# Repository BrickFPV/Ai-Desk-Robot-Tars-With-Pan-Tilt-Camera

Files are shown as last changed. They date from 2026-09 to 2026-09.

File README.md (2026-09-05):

# Tars AI Desk Robot
I wanted to create a sarcastic desk robot inspired from interstellar and also inspired from [Gptars on Youtube](https://www.youtube.com/@gptars) that you can ask things, chat with it, ask what is going on with the enviroment via camera that he can look around with 2 servos. And here it is. I didn't made a 3d printed case for it, I used lego technic to make a chasis. Total cost is about 80 dolars Now, here is step by step guide on how to make this robot:

### Please note that I haven't finished this project yet. So there might be some bugs.

## Features

- 🎤**Voice Interaction:** Low-latency STT via Whisper-large-v3-turbo and Orpheus TTS via Groq.
- 📸**Vision Recognition:** Qwen 2.5 72B vision integration to analyze camera input upon voice triggers.
- ⚙️ **Servo Control:** Smooth pan/tilt tracking via PCA9685 PWM driver board.
- 🌐**Web Search Integration:** Real-time information querying via DuckDuckGo Search API.
- 🔊**Pre-recorded Local Acknowledgments:** Pre-generated TTS wake-word acknowledgments to save API quota.

## **🔌 Needed Hardware**

- Raspberry Pi 4 1gb(Any other raspberry pi with atleast 1gb ram should work. I recommend having a heatsink or a cooler fan)
- Web cam(I used Logitech C270 but you can use any webcam that has a mic.)
- 2 Sg90 Servo Motors
- PCA9685 for controlling the servos
- 1s Lipo or 18650 li-on battery or a trustable 5V power source.
- MT3608(set the output to 5/5,1 volts) if you are using a lipo or 18650 because they output 4.2V max.(Look at **How to fix MT3608** part if the potentiometer on the board doesn't change the output voltage)
- MAX98357A amplifier
- Small speaker for the amp
- Breadboard
- 3D printed parts. Download links will be in the **Downloadables** folder.
- Lego techinc to make the chasis. The lego model will be in the **Downloadables** folder. (i would be pleased if someone makes a 3d printed chasis)

## **Setting Up The Chasis**

legorender
legorender_2
legorender_3

### Step 1: 3D printing and making the servo to be able to connect with lego
First, you need to download and 3D print the stl files (print both of them atleast 2 times because you have two servos with PLA [here](downloadables/3dprint).

After that, you have to screw both the servos to the SG90 shell using the small screws you get when buying a sg90 servo motor.(Make sure the output side on the servo is next to the 2 holes)

Then, put some super glue on the SG90 to lego's middle hole on the side where you can put it to sg90's output. after you put some super glue in the hole, put the Sg90-lego adapter(middle hole where you put glue on) to 
servo's output. Make sure to not push too much as if the glue touches the blue servo motor case, it might glue the motor output and the case and make it not moveable.


 
Adsız

### Step 2: Building the chasis

Download the [lego.io](downloadables/lego.io) Also, download Studio 2.0 from bricklink's [official website](https://store.bricklink.com/v2/studio/download.page)
You can look at the model there and improvise. You don't need to make the same thing. After making the chasis, and pan/tilt sections, fix the webcam on top of the pan section with rubber bands like this:




Then, asemble the two pieces(pan/tilt with camera) together like this:





After that, you can assemble the pan/tilt section with the servo motor on the main body. And after you do the wiring that i explain bellow, it should look like this: 







## **⚡ Wiring**

Here is the Raspberry pi 4 pinout to make things easier.
GPIO-Pinout-Diagram-2

First, just like in any other project, wire GND(PIN 6) to a power rail.

### The wiring for MAX98357a will be like this:

Vin ------ PIN 2(5V power)

Gnd ------ GND power rail

SD  ------ Empty

Gain ----- Gnd power rail

DIN ------ GPIO 21(PIN 40)

BCLK ----- GPIO 18(PIN 12)

LRC ------ GPIO 19(PIN 35)

Output + = Speaker +

Output - = Speaker -

### ---------------------The wiring for PCA9685:-------------------------

 Gnd ----- Gnd power rail
 
 Oe ------ Empty
 
 SCL ----- GPIO 3(PIN 5)
 
 SDA ----- GPIO 2(PIN 3)
 
 VCC ----- 3v3 power (PIN 1)
 
 Power terminal V+ = External 5v power source or 1s lipo wired to Mt3608(output voltage must be set to 5/5,1 volts)
 
 Power terminal - = External 5v power source or 1s lipo wired to Mt3608(output voltage must be set to 5/5,1 volts)

 **IMPORTANT: DO NOT WIRE THE POWER TERMINALS DIRECTLY TO 5V POWER ON RASPBERRY PI AS IT WILL DRAW TOO MUCH POWER AND MAY BURN YOUR BOARD**

 Pan Servo motor = The 3 pins on the very left(Match the colors)
 
 Tilt Servo motor = The 3 pins right next to the pan servo motor pins(Match the colors)servo

 ### ----------------------📷 Wiring for the usb webcam---------------

 Just plug the usb to the raspberry pi :)

## **🔧 How to fix MT3608**

If the potentiometer on the MT3608 doesn't change the output voltage, add a solder bridge at the back of the board as shown on the picture.

mt fix

## 🚀Setup

### Notes before we begin
#### *Get a free api key [here](https://groq.com)*
#### *Make sure you have [Raspberry Pi Connect](https://connect.raspberrypi.com) ready to make things easier*

(I will make an installer in the future)

*Assuming that you have raspberry pi os flashed and ready.(With gui you can disable the gui in the future if you want)*

Run the following commands in the Raspberry Pi terminal to enable the I2C interface for servo driving and install system audio/video dependencies:

```
sudo raspi-config nonint do_i2c 0
sudo apt update
sudo apt install -y python3-pip python3-venv python3-dev portaudio19-dev libasound2-dev alsa-utils ffmpeg vlc
```

Then, create the project workspace and install the libraries:

```
mkdir -p ~/tars_robot && cd ~/tars_robot
python3 -m venv venv
source venv/bin/activate
pip install --upgrade pip
pip install groq opencv-python pyaudio numpy adafruit-circuitpython-servokit duckduckgo_search
```

Create the main application file inside ~/tars_robot/tars.py:

```
nano tars.py
```

Copy and paste the tars.py code from [here](tars.py). And replace **PLACE YOUR GROQ API KEY HERE** on **line 82** with your Groq api key and save(Ctrl+O, Enter, Ctrl+X).

### ⚠DON'T RUN THE CODE YET

Create the generate_acks.py to generate "HUH?","YES?","THATS ME" and other bunch of words when you say "Hey Tars" and paste [this code](generate_acks.py)

**Again, replace "PLACE YOUR GROQ API KEY HERE" on line 5 with your Groq api key**

```
nano generate_acks.py
```

Now, make sure you are on (venv):

```
source venv/bin/activate
```

Then, run generate_acks.py **ONE** time:

```
python generate_acks.py
```

Now, you can run tars.py in (venv) whenever you want:

```
python tars.py
```

### Continue this guide if you want a shortcut and not get into (venv) when you want to run the code!

Exit from (venv):

```
deactivate
```

Create a shell script named run_tars.sh inside your project directory:

```
nano ~/run_tars.sh
```

Paste the following contents (update /home/pi/tars to your actual project folder path):

```
#!/bin/bash
cd /home/pi/tars
source venv/bin/activate
python tars.py

# Keeps the terminal window open if the script exits or crashes
echo ""
read -p "Press [Enter] to close..."
```

Make the script executable:

```
chmod +x ~/run_tars.sh
```

Create a file named TARS.desktop in your desktop. Open it with text editor and paste this code:

### **Replace "YOURUSERNAME" with opperating systems username**

```
[Desktop Entry]
Type=Application
Name=TARS Robot
Comment=Start TARS Voice & Vision Assistant
Exec=/home/YOURUSERNAME/run_tars.sh
Icon=utilities-terminal
Terminal=true
Categories=Development;
```

Make the shortcut file executable:

```
chmod +x ~/Desktop/TARS.desktop
```

Now you can double click and launch tars easily.

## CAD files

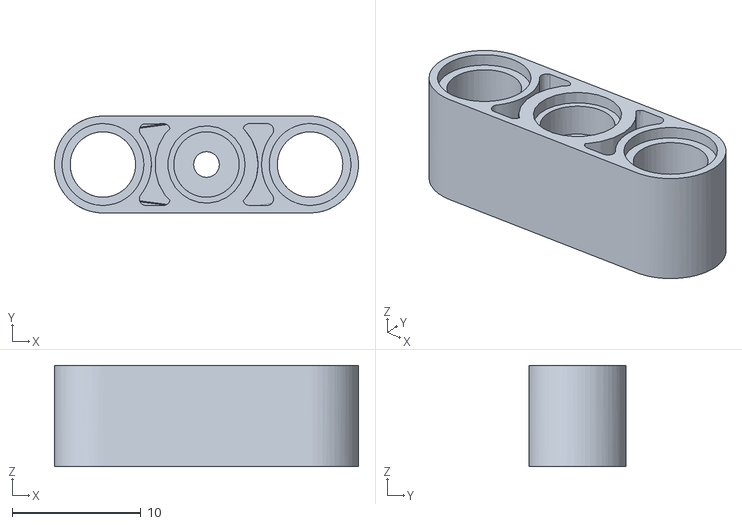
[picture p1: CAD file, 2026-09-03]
downloadables/3dprint/SG90 to lego.stl
23.6 x 7.52 x 7.85

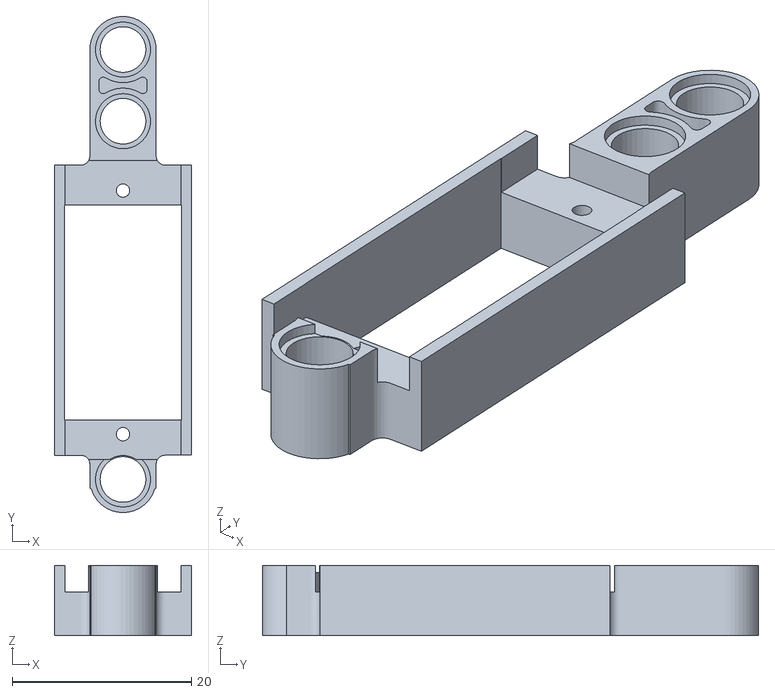
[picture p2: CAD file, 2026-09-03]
downloadables/3dprint/SG90 Shell.stl
15.3 x 55.4 x 7.85

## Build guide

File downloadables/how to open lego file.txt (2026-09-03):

To open the lego chasis file, download Studio 2.0 from bricklink's official site: https://store.bricklink.com/v2/studio/download.page

Then open the lego.io file in the Studio App.

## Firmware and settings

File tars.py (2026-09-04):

import asyncio
import io
import os
import sys
import wave
import subprocess
import ctypes
import random
import time
import json
import base64
import cv2
import numpy as np
import pyaudio
from datetime import datetime, timezone, timedelta

# Improved import order for ddgs library
try:
    from ddgs import DDGS
except ImportError:
    from duckduckgo_search import DDGS

from groq import AsyncGroq
from contextlib import contextmanager

# --- SERVO CONTROLLER (PCA9685 via ServoKit) ---
SERVO_ENABLED = False
try:
    from adafruit_servokit import ServoKit
    kit = ServoKit(channels=16)
    SERVO_ENABLED = True
    print("[PCA9685 Servo Controller Initialized Successfully]")
except Exception as e:
    print(f"[PCA9685 Servo Warning]: Could not initialize ServoKit ({e}). Servos disabled.")

# --- C-LEVEL ALSA ERROR SUPPRESSION ---
ERROR_HANDLER_FUNC = ctypes.CFUNCTYPE(None, ctypes.c_char_p, ctypes.c_int, ctypes.c_char_p, ctypes.c_int, ctypes.c_char_p)
def py_error_handler(filename, line, function, err, fmt):
    pass
c_error_handler = ERROR_HANDLER_FUNC(py_error_handler)

try:
    asound = ctypes.cdll.LoadLibrary('libasound.so.2')
    asound.snd_lib_error_set_handler(c_error_handler)
except Exception:
    pass

os.environ["PA_ALSA_PLUGINS_DISABLE"] = "1"
os.environ["PYTHONUNBUFFERED"] = "1"

# Keywords that trigger playback interruption during TTS speech
INTERRUPT_KEYWORDS = ["hey tars", "tars", "stop", "wait"]

# Keywords that trigger returning to wake-word standby mode
EXIT_KEYWORDS = [
    "stop the conversation", "stop conversation", "stop", 
    "cancel", "never mind", "nevermind", "exit", "bye", "goodbye", "go to standby"
]

def is_exit_command(text: str) -> bool:
    """Checks if user prompt requests ending the conversation session."""
    text_lower = text.lower().strip()
    return any(kw in text_lower for kw in EXIT_KEYWORDS)


@contextmanager
def suppress_stderr():
    """Redirects low-level ALSA/PyAudio stderr warnings to /dev/null."""
    try:
        null_fd = os.open(os.devnull, os.O_WRONLY)
        old_stderr = os.dup(2)
        os.dup2(null_fd, 2)
        os.close(null_fd)
        yield
    finally:
        os.dup2(old_stderr, 2)
        os.close(old_stderr)

# ==========================================
# --- CONFIGURATION & KEYS -----------------
# PLACE YOUR GROQ API KEY
GROQ_API_KEY = "PLACE YOUR GROQ API KEY HERE"

# Groq Orpheus TTS Voice Options: "troy", "daniel", "austin", "hannah", "diana", "autumn"
GROQ_TTS_MODEL = "canopylabs/orpheus-v1-english"
GROQ_TTS_VOICE = "troy"

TURKEY_TZ = timezone(timedelta(hours=3))
ACK_DIR = os.path.join(os.path.dirname(__file__), "acks")
TEMP_WAV_PATH = "/tmp/tars_tts_speech.wav"

# VAD Tuning Parameters
SILENCE_THRESHOLD = 400     # Silence threshold for user speech
INTERRUPT_THRESHOLD = 1200  # Voice threshold to trigger interruption during TTS output
SILENCE_DURATION = 0.6      # Seconds of silence before stopping recording early
MAX_RECORD_TIME = 6.0       # Maximum clip duration hard limit

# Servo Motion Calibration - MAXIMUM RANGE LIMITS
PAN_CHANNEL = 0
TILT_CHANNEL = 1

PAN_CENTER = 90
TILT_CENTER = 90

PAN_RIGHT = 20    # Maximum right limit
PAN_LEFT = 160    # Maximum left limit
TILT_UP = 150     # Maximum up limit
TILT_DOWN = 30    # Maximum down limit

# Global tracking of current head position
current_pan = PAN_CENTER
current_tilt = TILT_CENTER

# Vision trigger words
VISION_KEYWORDS = [
    "holding", "look", "see", "showing", "camera", "picture", 
    "photo", "what is this", "what am i", "view", "watch", "read",
    "describe", "what's", "what is"
]
# ==========================================

if GROQ_API_KEY == "PASTE_YOUR_GROQ_API_KEY_HERE":
    print("\n[ERROR] You need to paste your Groq API key into tars.py!")
    sys.exit(1)

client = AsyncGroq(api_key=GROQ_API_KEY)

# Audio Parameters (Logitech C270 USB Webcam Microphone Setup)
HW_CHANNELS = 1
HW_RATE = 16000
CHUNK = 1024

def find_webcam_mic_index(p):
    """Locates the Logitech C270 / USB Webcam input device index in PyAudio."""
    for i in range(p.get_device_count()):
        try:
            dev = p.get_device_info_by_index(i)
            name = dev.get('name', '').lower()
            if dev.get('maxInputChannels', 0) > 0:
                if 'c270' in name or 'webcam' in name or 'usb' in name:
                    return i
        except Exception:
            pass
    return None

# --- WEB SEARCH TOOL DEFINITION ---
WEB_SEARCH_TOOL = {
    "type": "function",
    "function": {
        "name": "web_search",
        "description": "Search the live internet for up-to-date facts, sports results, news, or current events.",
        "parameters": {
            "type": "object",
            "properties": {
                "query": {
                    "type": "string",
                    "description": "Search query keywords including current context."
                }
            },
            "required": ["query"]
        }
    }
}

# ==========================================
# --- SERVO MOTION CONTROL FUNCTIONS ------
# ==========================================
async def move_head_smooth(target_pan, target_tilt, speed=0.015):
    """Moves pan/tilt servos smoothly to target angles to prevent mechanical jerking."""
    global current_pan, current_tilt
    if not SERVO_ENABLED:
        return

    # Safety clamping to prevent servo over-rotation
    target_pan = max(20, min(160, target_pan))
    target_tilt = max(30, min(150, target_tilt))

    pan_steps = np.linspace(current_pan, target_pan, num=15)
    tilt_steps = np.linspace(current_tilt, target_tilt, num=15)

    for p_angle, t_angle in zip(pan_steps, tilt_steps):
        try:
            kit.servo[PAN_CHANNEL].angle = p_angle
            kit.servo[TILT_CHANNEL].angle = t_angle
            current_pan = p_angle
            current_tilt = t_angle
        except Exception:
            pass
        await asyncio.sleep(speed)

async def head_nod():
    """Nods head down and back to center."""
    await move_head_smooth(current_pan, max(30, current_tilt - 20), speed=0.01)
    await move_head_smooth(current_pan, min(150, current_tilt + 20), speed=0.01)

async def head_tilt_curious():
    """Tilts head slightly off-center when listening."""
    offset_pan = PAN_CENTER + random.choice([-15, 15])
    await move_head_smooth(offset_pan, TILT_CENTER + 15, speed=0.02)

async def head_center():
    """Resets head to forward center position."""
    await move_head_smooth(PAN_CENTER, TILT_CENTER, speed=0.015)

async def head_subtle_speak_movement():
    """Generates minor head movement while speaking to emulate lifelike presence."""
    rand_pan = max(30, min(150, current_pan + random.randint(-10, 10)))
    rand_tilt = max(40, min(140, current_tilt + random.randint(-6, 6)))
    await move_head_smooth(rand_pan, rand_tilt, speed=0.02)

def parse_directional_command(text: str):
    """
    Parses user input for directional movements.
    Re-centers unmentioned axes so single-direction commands move straight on that axis.
    Returns: (has_direction, target_pan, target_tilt, is_pure_movement)
    """
    text_lower = text.lower()
    
    # Default unmentioned axes to CENTER
    target_pan = PAN_CENTER
    target_tilt = TILT_CENTER
    
    has_horizontal = False
    has_vertical = False

    # Check horizontal directions (handles 'şeft' typo for 'left')
    if "right" in text_lower:
        target_pan = PAN_RIGHT
        has_horizontal = True
    elif "left" in text_lower or "şeft" in text_lower:
        target_pan = PAN_LEFT
        has_horizontal = True

    # Check vertical directions
    if "up" in text_lower or "higher" in text_lower:
        target_tilt = TILT_UP
        has_vertical = True
    elif "down" in text_lower or "lower" in text_lower:
        target_tilt = TILT_DOWN
        has_vertical = True

    has_direction = has_horizontal or has_vertical

    # Check center/reset request
    if any(w in text_lower for w in ["straight", "forward", "front", "center", "reset"]):
        target_pan = PAN_CENTER
        target_tilt = TILT_CENTER
        has_direction = True

    # Check if a question is being asked alongside the direction
    has_question = any(q in text_lower for q in [
        "what", "who", "where", "describe", "tell", "see", "read", "showing", "photo", "picture", "is on"
    ])

    # Pure movement = user commanded movement without asking a question
    is_pure_movement = has_direction and not has_question

    return has_direction, target_pan, target_tilt, is_pure_movement

# Initialize Head Position on Startup
if SERVO_ENABLED:
    try:
        kit.servo[PAN_CHANNEL].angle = PAN_CENTER
        kit.servo[TILT_CHANNEL].angle = TILT_CENTER
    except Exception:
        pass

# ==========================================

def capture_image_base64():
    """Captures a frame from USB webcam (Logitech C270) and returns base64 JPEG string."""
    try:
        cap = cv2.VideoCapture(0)
        if not cap.isOpened():
            print("\n[Camera Error]: Could not open webcam on /dev/video0", flush=True)
            return None

        for _ in range(5):
            ret, frame = cap.read()

        cap.release()

        if not ret or frame is None:
            print("\n[Camera Error]: Failed to capture image frame", flush=True)
            return None

        _, buffer = cv2.imencode('.jpg', frame, [int(cv2.IMWRITE_JPEG_QUALITY), 80])
        return base64.b64encode(buffer).decode('utf-8')
    except Exception as e:
        print(f"\n[Camera Error]: {e}", flush=True)
        return None

def is_vision_query(text: str) -> bool:
    """Checks if user prompt requests visual observation via webcam."""
    text_lower = text.lower()
    return any(kw in text_lower for kw in VISION_KEYWORDS)

def play_local_ack():
    """Plays a random pre-recorded acknowledgment WAV file locally."""
    if not os.path.exists(ACK_DIR):
        print("TARS: YES?", flush=True)
        return

    files = [f for f in os.listdir(ACK_DIR) if f.lower().endswith(".wav")]
    if not files:
        print("TARS: YES?", flush=True)
        return

    chosen_file = random.choice(files)
    filepath = os.path.join(ACK_DIR, chosen_file)

    display_name = os.path.splitext(chosen_file)[0].upper().replace("_", " ")
    print(f"TARS: {display_name}?", flush=True)

    try:
        subprocess.run(['aplay', '-q', filepath], stdout=subprocess.DEVNULL, stderr=subprocess.DEVNULL)
    except Exception as e:
        print(f"[Audio Error]: {e}")

def execute_web_search(query: str) -> str:
    """Performs a web search using DuckDuckGo."""
    try:
        results = DDGS().text(query, max_results=3)
        if not results:
            return "No internet search results found."
        formatted = "\n".join([f"- {r.get('title')}: {r.get('body')}" for r in results])
        return formatted
    except Exception as e:
        return f"Search error: {e}"

def process_pcm_to_mono_wav(raw_pcm):
    """Converts recorded 16kHz PCM directly into a WAV container for Whisper STT."""
    wav_io = io.BytesIO()
    with wave.open(wav_io, 'wb') as wf:
        wf.setnchannels(1)
        wf.setsampwidth(2)
        wf.setframerate(16000)
        wf.writeframes(raw_pcm)
    
    wav_io.seek(0)
    wav_io.name = "input.wav"
    return wav_io

def record_audio_smart(prompt_msg="", is_wake_word=False):
    """VAD recorder using Logitech C270 USB microphone."""
    if prompt_msg:
        print(prompt_msg, flush=True)

    with suppress_stderr():
        p = pyaudio.PyAudio()
        dev_idx = find_webcam_mic_index(p)
        
        stream_kwargs = {
            "format": pyaudio.paInt16,
            "channels": HW_CHANNELS,
            "rate": HW_RATE,
            "input": True,
            "frames_per_buffer": CHUNK
        }
        if dev_idx is not None:
            stream_kwargs["input_device_index"] = dev_idx

        stream = p.open(**stream_kwargs)

    frames = []
    has_spoken = False
    silence_start = None
    start_time = time.time()
    max_duration = 1.8 if is_wake_word else MAX_RECORD_TIME

    while True:
        data = stream.read(CHUNK, exception_on_overflow=False)
        frames.append(data)

        audio_chunk = np.frombuffer(data, dtype=np.int16)
        rms = np.sqrt(np.mean(audio_chunk.astype(np.float32)**2)) if len(audio_chunk) > 0 else 0

        if rms > SILENCE_THRESHOLD:
            has_spoken = True
            silence_start = None
        elif has_spoken:
            if silence_start is None:
                silence_start = time.time()
            elif time.time() - silence_start >= SILENCE_DURATION:
                break

        if time.time() - start_time >= max_duration:
            break

    with suppress_stderr():
        stream.stop_stream()
        stream.close()
        p.terminate()

    return b''.join(frames)

async def transcribe_audio(wav_file):
    """Speech-to-Text using whisper-large-v3-turbo via Groq API."""
    try:
        transcription = await client.audio.transcriptions.create(
            file=wav_file,
            model="whisper-large-v3-turbo",
            response_format="text",
            temperature=0.0
        )
        return transcription.strip()
    except Exception as e:
        print(f"\n[STT Error]: {e}")
        return ""

async def stream_tars_response(chat_history, image_b64=None):
    """Handles streaming responses from Groq with vision routing and thinking suppressed."""
    
    # -------------------------------------------------------------
    # VISION EXECUTION PATH (Qwen 3.6 27B)
    # -------------------------------------------------------------
    if image_b64:
        model_name = "qwen/qwen3.6-27b"
        
        last_msg = chat_history.pop()
        user_prompt_text = last_msg["content"] if isinstance(last_msg["content"], str) else "What do you see?"

        multimodal_msg = {
            "role": "user",
            "content": [
                {"type": "text", "text": user_prompt_text},
                {
                    "type": "image_url",
                    "image_url": {"url": f"data:image/jpeg;base64,{image_b64}"}
                }
            ]
        }
        chat_history.append(multimodal_msg)

        try:
            completion = await client.chat.completions.create(
                model=model_name,
                messages=chat_history,
                temperature=0.7,
                max_completion_tokens=256,
                reasoning_format="hidden",
                reasoning_effort="none",
                stream=True
            )
            
            in_think_block = False
            async for chunk in completion:
                delta = chunk.choices[0].delta.content
                if not delta:
                    continue

                if "<think>" in delta:
                    in_think_block = True
                    delta = delta.split("<think>")[0]
                if "</think>" in delta:
                    in_think_block = False
                    delta = delta.split("</think>")[-1]

                if not in_think_block and delta:
                    yield delta
            return
        except Exception as e:
            print(f"\n[Vision LLM Error]: {e}")
            yield "My optical sensors had a glitch."
            return

    # -------------------------------------------------------------
    # STANDARD TEXT & SEARCH EXECUTION PATH (GPT-OSS 120B)
    # -------------------------------------------------------------
    model_name = "openai/gpt-oss-120b"
    try:
        first_pass = await client.chat.completions.create(
            model=model_name,
            messages=chat_history,
            tools=[WEB_SEARCH_TOOL],
            tool_choice="auto",
            temperature=0.7,
            max_completion_tokens=256,
            reasoning_format="hidden",
            reasoning_effort="low"
        )

        msg = first_pass.choices[0].message

        if msg.tool_calls:
            assistant_msg = {
                "role": "assistant",
                "content": msg.content or "",
                "tool_calls": [
                    {
                        "id": tc.id,
                        "type": "function",
                        "function": {
                            "name": tc.function.name,
                            "arguments": tc.function.arguments
                        }
                    } for tc in msg.tool_calls
                ]
            }
            chat_history.append(assistant_msg)

            for tool_call in msg.tool_calls:
                if tool_call.function.name == "web_search":
                    args = json.loads(tool_call.function.arguments)
                    query = args.get("query", "")
                    print(f"\n[TARS Searching Internet: '{query}']...", flush=True)

                    search_result = await asyncio.to_thread(execute_web_search, query)
                    
                    chat_history.append({
                        "role": "tool",
                        "tool_call_id": tool_call.id,
                        "content": search_result
                    })

            # Pass WITH tools parameter to maintain tool call context schema requirement
            completion = await client.chat.completions.create(
                model=model_name,
                messages=chat_history,
                tools=[WEB_SEARCH_TOOL],
                temperature=0.7,
                max_completion_tokens=256,
                reasoning_format="hidden",
                reasoning_effort="low",
                stream=True
            )
            async for chunk in completion:
                delta = chunk.choices[0].delta.content
                if delta:
                    yield delta
        else:
            yield msg.content or ""

    except Exception as e:
        print(f"\n[LLM Error]: {e}")
        yield ""

async def generate_and_play_groq_tts(text, interrupt_event):
    """Sends text to Groq Orpheus TTS API, streams audio via aplay, and checks mic for wake/stop keywords."""
    if not text.strip() or interrupt_event.is_set():
        return True
    
    try:
        response = await client.audio.speech.create(
            model=GROQ_TTS_MODEL,
            voice=GROQ_TTS_VOICE,
            input=text,
            response_format="wav"
        )
        
        audio_bytes = await response.read()

        with open(TEMP_WAV_PATH, "wb") as f:
            f.write(audio_bytes)

        player_proc = subprocess.Popen(
            ['aplay', '-q', TEMP_WAV_PATH],
            stdout=subprocess.DEVNULL,
            stderr=subprocess.DEVNULL
        )

        # Trigger subtle head movement while TARS is speaking
        asyncio.create_task(head_subtle_speak_movement())

        with suppress_stderr():
            p = pyaudio.PyAudio()
            dev_idx = find_webcam_mic_index(p)
            stream_kwargs = {
                "format": pyaudio.paInt16,
                "channels": HW_CHANNELS,
                "rate": HW_RATE,
                "input": True,
                "frames_per_buffer": CHUNK
            }
            if dev_idx is not None:
                stream_kwargs["input_device_index"] = dev_idx

            mic_stream = p.open(**stream_kwargs)

        interrupted = False
        speaking_frames = []
        is_collecting_speech = False
        silence_start = None

        while player_proc.poll() is None:
            if interrupt_event.is_set():
                player_proc.terminate()
                player_proc.kill()
                interrupted = True
                break

            try:
                data = mic_stream.read(CHUNK, exception_on_overflow=False)
                audio_chunk = np.frombuffer(data, dtype=np.int16)
                rms = np.sqrt(np.mean(audio_chunk.astype(np.float32)**2)) if len(audio_chunk) > 0 else 0
                
                # Detect speech activity
                if rms > SILENCE_THRESHOLD:
                    if not is_collecting_speech:
                        is_collecting_speech = True
                        speaking_frames = []
                    speaking_frames.append(data)
                    silence_start = None
                elif is_collecting_speech:
                    speaking_frames.append(data)
                    if silence_start is None:
                        silence_start = time.time()
                    elif time.time() - silence_start >= 0.4:
                        # Pause detected: transcribe the captured snippet to test for interrupt words
                        is_collecting_speech = False
                        frames_to_check = list(speaking_frames)
                        speaking_frames = []
                        
                        wav_file = process_pcm_to_mono_wav(b''.join(frames_to_check))
                        transcript = await transcribe_audio(wav_file)
                        
                        if transcript:
                            text_lower = transcript.lower()
                            if any(kw in text_lower for kw in INTERRUPT_KEYWORDS):
                                print(f"\n[Interrupt Keyword Detected: '{transcript}']", flush=True)
                                player_proc.terminate()
                                player_proc.kill()
                                interrupt_event.set()
                                interrupted = True
                                break
            except Exception:
                pass

            await asyncio.sleep(0.001)

        with suppress_stderr():
            mic_stream.stop_stream()
            mic_stream.close()
            p.terminate()

        return interrupted
    except Exception as e:
        print(f"\n[Groq TTS Error]: {e}")
        return False
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

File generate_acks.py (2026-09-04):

import asyncio
import os
from groq import AsyncGroq

GROQ_API_KEY = "PLACE YOUR GROQ API KEY HERE"
GROQ_TTS_MODEL = "canopylabs/orpheus-v1-english"
GROQ_TTS_VOICE = "troy"

ACK_DIR = os.path.join(os.path.dirname(__file__), "acks")
ACK_PHRASES = ["HUH?", "YES?", "YOU CALLED?", "GO ON", "THATS ME"]

client = AsyncGroq(api_key=GROQ_API_KEY)

async def generate_acks():
    os.makedirs(ACK_DIR, exist_ok=True)
    for phrase in ACK_PHRASES:
        filename = phrase.lower().replace("?", "").replace(" ", "_") + ".wav"
        filepath = os.path.join(ACK_DIR, filename)
        response = await client.audio.speech.create(
            model=GROQ_TTS_MODEL,
            voice=GROQ_TTS_VOICE,
            input=phrase,
            response_format="wav"
        )
        audio_bytes = await response.read()
        with open(filepath, "wb") as f:
            f.write(audio_bytes)
    print("Offline acknowledgments generated in 'acks/' directory.")

if __name__ == "__main__":
    asyncio.run(generate_acks())
